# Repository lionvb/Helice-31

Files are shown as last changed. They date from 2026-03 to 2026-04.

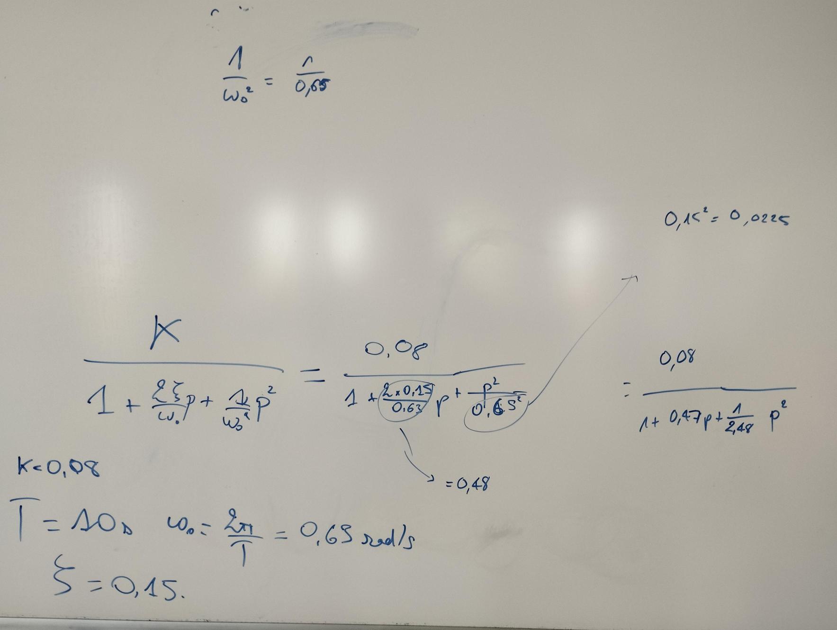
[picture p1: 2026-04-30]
MatLab/image.jpg

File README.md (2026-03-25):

# 🚁 Hélice 31 — Démonstrateur Hélicoptère Asservi

> Maquette transportable de démonstration des compétences en automatique et systèmes embarqués, destinée aux salons et Journées Portes Ouvertes (JPO).

---

## 📋 Présentation du projet

Ce projet consiste à concevoir et réaliser un **démonstrateur interactif en forme d'hélicoptère** capable d'illustrer les compétences E2 en automatique (asservissement PID) et en systèmes embarqués (acquisition, traitement temps réel, commande moteur). La maquette est dimensionnée pour être facilement transportable (≈ 30 × 30 cm) et peut être manipulée en direct par les visiteurs via un boîtier de commande.

---

## 🎯 Objectifs

- Démontrer un **asservissement sur deux axes** (tanguage + anti-couple, comme un quadricoptère)
- Permettre le **réglage en temps réel** des gains PID (Kp, Ki, Kd) par potentiomètres
- Offrir une interface de commande intuitive (potentiomètre ou manette radiofréquence)
- Assurer une **commande numérique temps réel** avec une période d'échantillonnage définie par interruption timer
- Basculer entre correcteur **analogique** et **numérique** 

---

## 🏗️ Architecture du système

```
┌─────────────────────────────────────────────────────────────┐
│                    BOÎTIER DE COMMANDE                       │
│   [Potentiomètre consigne]  [Pot. Kp]  [Pot. Ki]  [Pot. Kd] │
│   [Manette RF optionnelle]                                   │
└─────────────────────────┬───────────────────────────────────┘
                          │  (consigne + gains)
                          ▼
              ┌───────────────────────┐
              │       ARDUINO         │
              │  ┌─────────────────┐  │
              │  │  Timer / IRQ    │  │  ← Période d'échantillonnage fixe
              │  │  Correcteur PID │  │
              │  │  numérique      │  │
              │  └────────┬────────┘  │
              └───────────┼───────────┘
                          │
          ┌───────────────┼───────────────┐
          ▼               ▼               ▼
   [Moteur principal]  [Rotor anticouple]  [LEDs état]
   (tanguage / lift)   (anti-couple)    (saturation, etc.)
          │
          ▼
   [MPU-6050 — mesure angles]
          │
          └──────────────► feedback vers Arduino 
```

### Logique de commande anti-couple 

| Action sur le rotor anticouple | Effet |
|---|---|
| Diminution de la vitesse | Rotation plus lente dans le sens du couple réactif |
| Augmentation de la vitesse | Rotation dans le sens inverse (compensation accrue) |

---

## 🔧 Matériel

| Composant | Rôle | Remarques |
|---|---|---|
| **Arduino** | Unité de traitement centrale | Gestion timers, PID, PWM |
| **MPU-6050** | Gyroscope / accéléromètre | Mesure des angles à intervalle régulier |
| **Moteurs Brushless** | Propulsion (principal + rotor de queue) | ⚠️ Initialiser à 0 pour déverrouiller la sécurité ESC |
| **ESC** | Contrôleurs moteurs brushless | Signal PWM depuis Arduino |
| **Potentiomètres (×4 min.)** | Consigne + réglage Kp, Ki, Kd | Réglage en direct |
| **Manette RF** | Commande sans fil optionnelle | Module RF à intégrer |
| **Batterie LiPo** | Alimentation moteurs | En premier lieu : générateur de labo |
| **Hélices** | 2 modèles disponibles | Format dirigeable et format drone |
| **LEDs** | Indicateurs d'état | Saturation commande, modes, alarmes |
| **Structure** | Châssis de la maquette | Impression 3D — ≈ 30 × 30 cm |

---

## 💻 Logiciel & Algorithmes

### Boucle de contrôle

La boucle de régulation tourne à **période fixe**, déclenchée par une interruption timer sur l'Arduino :

```
IRQ Timer (période T)
  ├── Lecture MPU-6050 (angle mesuré θ)
  ├── Lecture potentiomètre consigne (θ_ref)
  ├── Lecture Kp, Ki, Kd (potentiomètres dédiés)
  ├── Calcul erreur : e = θ_ref - θ
  ├── Calcul correcteur PID numérique
  ├── Saturation + indication LED
  └── Envoi commande PWM vers ESC
```

---

## 🔩 Points critiques de conception

- **Frottements aux jonctions** : à minimiser impérativement pour ne pas perturber la dynamique
- **Légèreté du montage** : impact direct sur les performances - privilégier l'impression 3D 
- **Sécurité ESC brushless** : les moteurs doivent être initialisés à **0** (signal neutre) pour déverrouiller la sécurité électronique

---

## 📐 Modélisation

Le projet inclut une **double modélisation** :
- Modèle **mécanique / physique** de la maquette (dynamique des rotors, couples, inerties)
- Modèle **Matlab** pour la simulation et la synthèse des correcteurs

---

## 💡 Indicateurs LED

| LED | Signification |
|---|---|
| 🔴 Rouge | Saturation de la commande moteur |

---

## 📅 Planning

| Date | Séance | Contenu |
|---|---|---|
| 19/03 | S1 | Spécification & planning |
| 26/03 | S2 | Étude, CAO, Arduino, schéma global |
| 02/04 | S3 | Intégration / Consigne |
| 23/04 | S4 | Modélisation |
| 30/04 | S5 | Soutenance + Making-off|

---

## ⚠️ Règles de sécurité

1. **Ne jamais tester avec des hélices montées sans la présence d'un enseignant.**
2. Toujours initialiser les ESC à la position neutre (commande = 0) avant mise sous tension.
3. En premier prototype, utiliser un **générateur de laboratoire** (pas de batterie LiPo).
4. Vérifier les réglages PID en simulation Matlab avant de les appliquer sur la maquette réelle.
5. S'assurer que la structure est solidement fixée avant tout essai moteur.

---

## 📚 Références & Ressources

- [Maquette existante — Lien 1](#) *(à compléter)*
- [Maquette existante — Lien 2](#) *(à compléter)*
- Documentation MPU-6050 (InvenSense)
- Documentation Arduino (timers, interruptions)
- Datasheet ESC brushless utilisé

---

*Projet **Hélice 31** — réalisé dans le cadre de la formation — Compétences E2 — Automatique & Systèmes Embarqués en collaboration avec M. Trenchant*

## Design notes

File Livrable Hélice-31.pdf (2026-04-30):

Projet Science de l’ingénieur — Livrable Technique
T. BERNARD, F. COG, N.Coudry, L.BOUYAHI, L.QUIBEUF, V.BON & A.KEMPNICH

# PROJET DE SCIENCE DE L'INGÉNIEUR

## Hélice 31

LIVRABLE TECHNIQUE

De la découverte des composants jusqu'à la maquette physique

Équipe Projet

Tristan BERNARD
Fatihhan COG
Nils COUDRY
Loan BOUYAHI
Louis QUIBEUF
Victor BON
Arthur KEMPNICH

Informations

Domaine : Science de l’ingénieur (SI) Durée : 5 séances
Simulation :
Matériel Principal : Arduino Uno

Ce document est un rapport d'avancement détaillé de notre projet.

Projet Science de l’ingénieur — Hélice-31

## Sommaire

Section | Titre | Page
0 | Page de Garde | 1
Sommaire | Sommaire | 2
1 | Contexte | 3
2 | La théorie — Comprendre avant de construire | 4
2.1 | Le Cerveau et L'Échantillonnage : La carte Arduino | 4
2.2 | Les Sens : Le Gyroscope / Accéléromètre | 4
2.3 | Les Actionneurs : Moteur Brushless et ESC | 4
2.4 | L'Interface Humain-Machine (IHM) : Potentiomètres et Bouton | 5
2.5 | La Signalisation : LED et Résistance | 5
3 | Journal de Bord — Avancement séance par séance | 6
4 | Architecture Technique du Montage | 7
4.1 | Composants | 7
4.2 | Schéma Électronique | 8
4.2.1 | Version avec TM1637 | 8
4.2.2 | Version avec LED | 9
4.3 | Montage Réel | 9-10
5 | Explication du code | 11
5.1 | Découpage Modulaire du Code | 11
5.2 | L'Échantillonnage Temps Réel | 11
5.3 | Modélisation du Correcteur PID Numérique | 11-12
5.4 | Traitement du Signal | 12
5.5 | Interface Homme-Machine et Sécurité | 12
5.6 | Modélisation Numérique et Simulation | 13
5.7 | Obtention des données avec notre montage | 13
6 | MatLab | 14
6.1 | Diagnostic et identification du Système (Boucle Ouverte) | 14
6.2 | Synthèse du Correcteur (La Compensation de Pôles) | 14
6.3 | Validation et analyse des résultats | 14-15
7 | Conclusion | 16
8 | Note de l'Équipe | 17

## 1. Contexte et Cahier des Charges

Ce projet s'inscrit dans le cadre de la mise en pratique et de la valorisation des compétences de la filière E2. L'objectif principal est de concevoir un démonstrateur technique attractif et transportable, destiné à être exposé lors de salons et de Journées Portes Ouvertes (JPO). Prenant la forme d'une maquette d'hélicoptère d'environ 40 par 40 centimètres (réalisée en impression 3D), ce système a pour but d'illustrer concrètement les principes d'asservissement sur deux axes.

D'un point de vue technique, le système s'affranchit d'un pilotage direct depuis Simulink au profit d'une commande numérique embarquée autonome basée sur une carte Arduino et un gyroscope MPU 6050. Le pilotage s'effectuera via un boîtier de commande radiofréquence. L'un des aspects les plus didactiques de ce démonstrateur est sa capacité à être réglé "en direct" : l'utilisateur pourra ajuster les coefficients du correcteur PID (Kp, Ki, Kd) à l'aide de potentiomètres dédiés afin d'observer immédiatement l'impact sur la stabilité, avec l'aide de LED signalant notamment la saturation de la commande. La boucle d'asservissement reposera sur un échantillonnage rigoureux, utilisant les timers (interruptions) pour cadencer la mesure des angles et l'envoi des consignes aux moteurs brushless.

Le développement de cette maquette implique également de relever des défis mécaniques et physiques importants. Une double modélisation est nécessaire : la commande du tangage par le rotor principal génère un couple qui fait tourner la structure. Cette rotation parasite doit être compensée par un rotor de queue dont les variations de vitesse permettront de diriger l'appareil. La réussite du projet reposera sur la minimisation des frottements aux jonctions et sur l'optimisation du poids de l'ensemble.

Enfin, la réalisation de ce projet suivra une méthodologie stricte, débutant par un prototypage sur breadboard. Pour des raisons évidentes de sécurité, aucun test impliquant les hélices ne sera toléré sans la supervision du professeur (avec une attention particulière portée à l'initialisation des moteurs brushless). Le développement autorise l'usage de la documentation en ligne et de l'intelligence artificielle générative, à condition que cette dernière soit utilisée avec discernement (pour éviter les erreurs de génération) et que son usage soit explicitement sourcé. Si le besoin s'en fait sentir, une évolution prévoyant la bascule entre un correcteur analogique et numérique pourra être étudiée en collaboration (tâche attribuable à M. Trenchant).

## 2. La Théorie — Comprendre Avant de Construire

Pour que le démonstrateur "Hélice-31" puisse s'auto-stabiliser selon ses deux axes (tangage et lacet), il est nécessaire de créer une boucle d'asservissement complète. Cette boucle repose sur des composants matériels précis qui interagissent en temps réel. Voici le rôle théorique et physique de chacun d'entre eux.

### 2.1 Le Cerveau et l'Échantillonnage : La Carte Arduino

L'Arduino est le microcontrôleur au cœur du système. Son rôle théorique n'est pas seulement de lire des valeurs, mais d'exécuter la commande numérique.

Dans un système asservi informatiquement, le temps n'est pas continu mais discret. L'Arduino utilise ses timers internes et des interruptions pour définir une période d'échantillonnage stricte (par exemple, toutes les 10 ou 20 ms). À chaque "tic" d'horloge, il exécute la même boucle :

1. Mesure de l'erreur (via le gyroscope).
2. Calcul du correcteur PID.
3. Envoi de la nouvelle consigne aux moteurs.
Cette régularité est indispensable pour que les calculs mathématiques d'intégration (pour le Ki) et de dérivation (pour le Kd) soient justes.

### 2.2 Les Sens : Le Gyroscope / Accéléromètre

Le MPU6050 est une centrale à inertie (IMU) qui permet de mesurer l'angle réel de la maquette.

- Le Gyroscope : Mesure la vitesse de rotation angulaire (en degrés par seconde). Il est ultra-réactif mais accumule des erreurs dans le temps (dérive).
- L'Accéléromètre : Mesure le vecteur de la gravité terrestre pour donner un angle absolu par rapport au sol. Il est très sensible aux vibrations des moteurs.
- Théorie d'utilisation : Le code de l'Arduino devra utiliser un filtre mathématique (souvent un "Filtre Complémentaire") pour fusionner ces deux données et obtenir un angle stable et précis, qui servira de retour pour la boucle d'asservissement.

### 2.3 Les Actionneurs : Moteur Brushless et ESC

Contrairement à un petit moteur à courant continu basique, un moteur "Brushless" (sans balais) est un moteur triphasé. Il ne peut pas fonctionner en le branchant directement sur une batterie.

- L'ESC (Electronic Speed Controller) : C'est le variateur électronique. Il transforme le courant continu de l'alimentation en impulsions triphasées pour faire tourner le moteur.
- Contrôle et Sécurité : L'ESC se pilote via un signal PWM (généré par l'Arduino). Point critique de spécification : Par sécurité absolue (surtout lors de l'utilisation d'hélices), un ESC possède une sécurité au démarrage. Il exige de recevoir un signal correspondant à "0% de puissance" pendant quelques secondes à l'allumage pour s'armer, sinon il bloque le moteur.

### 2.4 L'Interface Humain-Machine (IHM) : Potentiomètres et Bouton

Le boîtier de commande permet d'interagir avec le système numérique en temps réel, sans avoir à recompiler le code.

- Le Potentiomètre : Sur le plan théorique, c'est un pont diviseur de tension. L'Arduino lit une tension analogique comprise entre 0V et 5V, qu'il convertit en une valeur numérique (de 0 à 1023).
Vout = Vin*(R2/(R1+R2)
Dans notre projet, ils auront deux rôles : définir la consigne de vol (le point d'équilibre désiré), et surtout, régler en direct les coefficients Kp, Ki et Kd de l'asservissement.
- Le Bouton poussoir : Il servira d'entrée numérique logique (0 ou 1) pour déclencher des actions spécifiques (réinitialisation des intégrateurs du PID, bascule entre modes analogique/numérique, ou arrêt d'urgence).

### 2.5 La Signalisation : LED et Résistance

Les LEDs permettront un diagnostic visuel rapide de l'état du système (ex: LED allumée si la commande sature, signifiant que le moteur est à 100% de ses capacités mais n'arrive pas à atteindre la consigne).

- La Résistance de protection : Une LED est un composant non linéaire qui ne limite pas le courant qui la traverse. Sans résistance, elle grillerait instantanément. La valeur de la résistance est calculée grâce à la loi d'Ohm pour limiter ce courant :
U = R*I
(Où U est la tension aux bornes de la résistance, et I le courant souhaité pour la LED).

## 3. Journal de Bord — Avancement Séance par Séance

Séance 1

Découverte du projet
- Découverte du projet et du cahier des charges.
- Attribution des tâches au sein de l'équipe et découverte du matériel.
- Premières idées et ébauche du schéma de principe (sur papier).

Séance 2

Etude du matériel
- Étude technique approfondie du matériel.
- Début du schéma électronique.
- Initialisation de l'architecture du code Arduino.

Séance 3

Finalisation schéma et début montage
- Finalisation du schéma électronique et de ses variations.
- Début du montage matériel sur breadboard.
- Amélioration et développement de la logique du code.

Séance 4

Finalisation schéma et code
- Prototype matériel terminé.
- Tests de validation des signaux et du code sans hélice pour des raisons de sécurité.
- Compilation et rédaction de la version finale du livrable.

Séance 5

Soutenance
- Présentation orale devant jury.
- Démonstration du montage fonctionnel.

## 4. Architecture Technique du Montage

### 4.1 Composant

Composant | Rôle
Carte Arduino | Le cerveau du système. Elle exécute le code en temps réel, lit les données des capteurs et des potentiomètres, calcule l'asservissement et envoie les ordres de puissance aux moteurs
Moteur Brushless | L'actionneur mécanique. Il transforme l'énergie électrique en une rotation mécanique à très haute vitesse. Il ne possède pas de frottements internes (pas de balais), ce qui le rend ultra-réactif pour stabiliser la maquette.
ESC | Le traducteur de puissance. L'Arduino ne peut pas alimenter directement un gros moteur. L'ESC reçoit le signal de commande faible (PWM) de l'Arduino et libère l'énergie correspondante du générateur vers le moteur sous forme de courant triphasé.
Potentiomètre | L'interface de commande. Il agit comme un diviseur de tension variable. Il permet à l'opérateur de donner une consigne de vol ou de régler en direct les coefficients mathématiques du système.
LED | L'indicateur de diagnostic. Elle fournit un retour visuel instantané (ex: allumée quand le système est initialisé, clignotante lors d'une saturation de commande ou d'une erreur technique).
Bouton | L'entrée logique (0 ou 1). Dans notre projet, le bouton poussoir ne sert pas uniquement de simple interrupteur, mais de sélecteur de mode (bouton modal). Cette approche logicielle permet de maximiser l'utilisation d'un seul potentiomètre pour contrôler plusieurs paramètres du système.
Gyroscope (MPU-92.65) (Changement par manque de matériel) | Le capteur d'attitude. Il mesure en permanence l'accélération terrestre et la vitesse de rotation de la maquette. Il permet au système de connaître son angle exact d'inclinaison physique pour fermer la boucle d'asservissement.
Hélice | Le convertisseur aérodynamique. Elle transforme la rotation mécanique du moteur Brushless en force de poussée. C'est elle qui crée la force physique permettant au bras articulé de vaincre la gravité.
BreadBoard | Le support de prototypage. Elle permet de connecter tous les composants électroniques de manière sécurisée et rapide, sans aucune soudure, ce qui est idéal pour faire des tests ou corriger le schéma.
Cable | Les fils assurent deux missions : transporter l'énergie électrique (VCC, GND) et acheminer les signaux d'information (données des capteurs, signaux PWM) entre la carte et les périphériques.
Générateur | La source d'énergie constante. Utilisé à la place d'une batterie, il garantit une tension électrique parfaitement stable pendant les tests, évitant ainsi que la baisse de tension d'une batterie qui se vide ne fausse le comportement des moteurs et les calculs d'asservissement.

### 4.2 Schéma Électronique

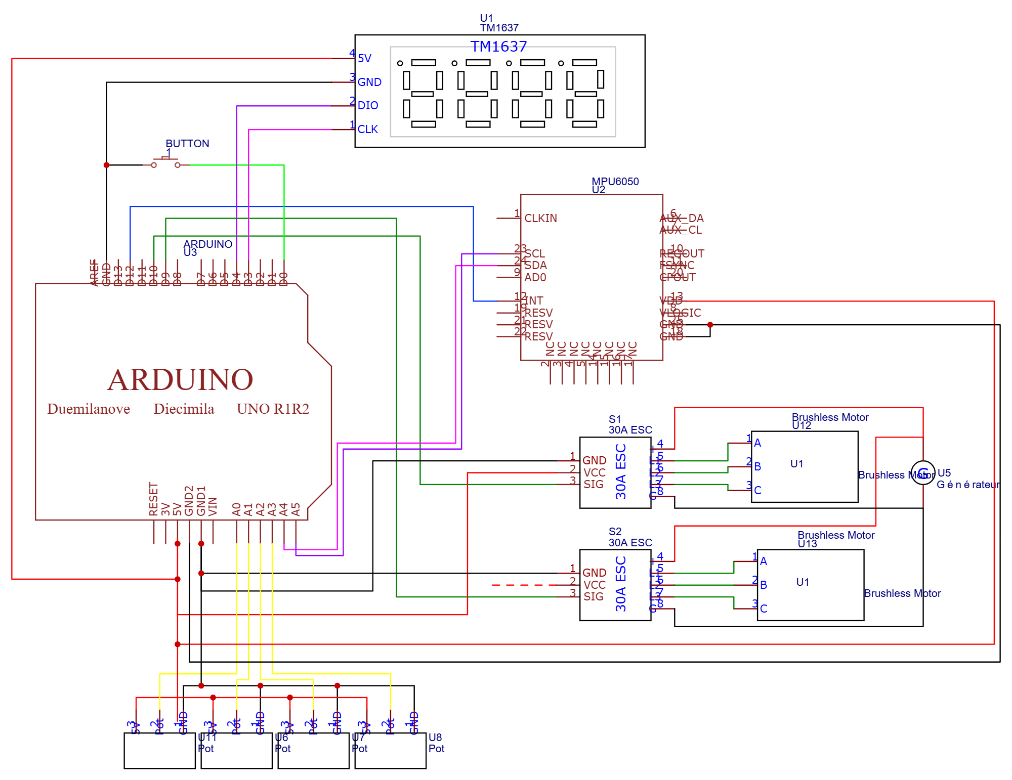
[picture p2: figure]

4.2.1 Version avec TM1637 :

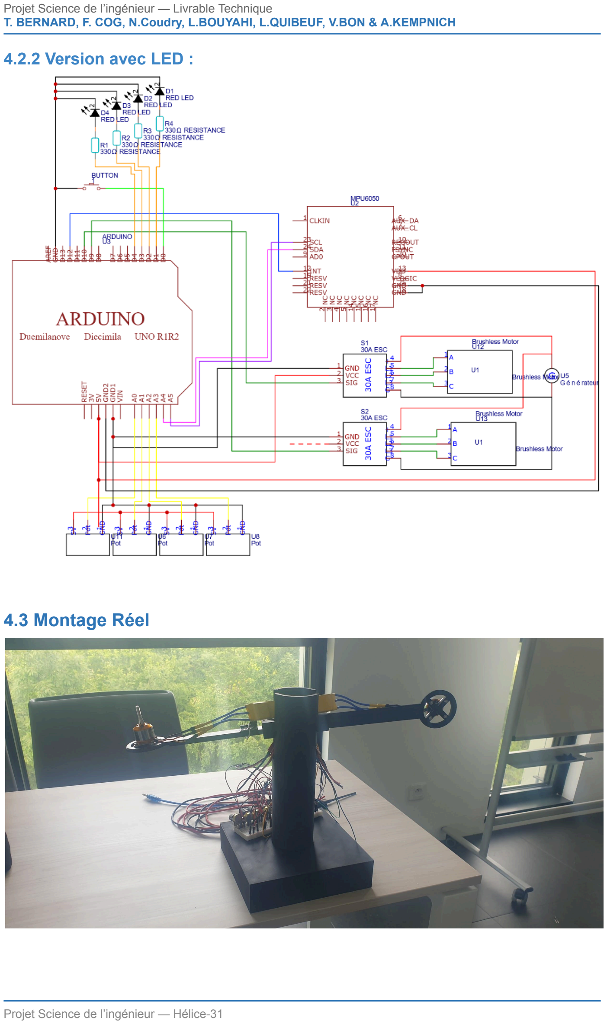
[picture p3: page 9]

### 4.2.2 Version avec LED :

### 4.3 Montage Réel

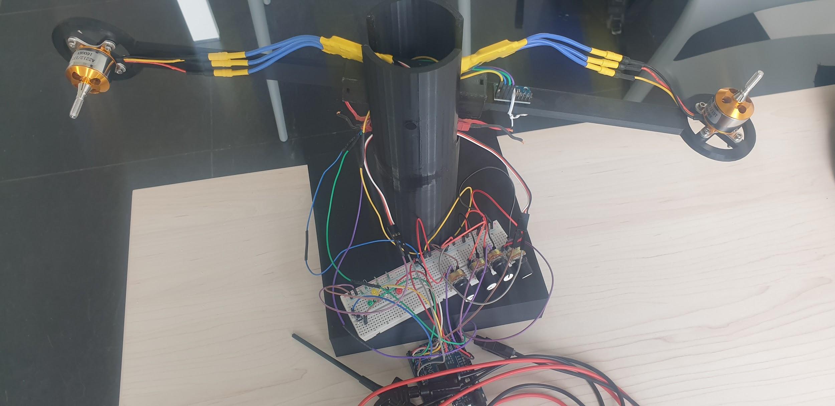
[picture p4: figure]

## 5. Explication du code

### 5.1 Découpage Modulaire du Code

Le projet est divisé en plusieurs fichiers distincts pour séparer la configuration, les mathématiques, la lecture des capteurs et le pilotage des actionneurs.

Module | Fichiers | Rôle technique
Programme Principal | Helice31.ino | Contient les boucles setup() et loop(). Il orchestre l'appel de toutes les fonctions selon un ordonnancement précis dicté par les interruptions du Timer.
Configuration | config.h | Regroupe toutes les constantes du système : période d'échantillonnage (Te = 0.1s), affectation des broches (Pins), limites PWM et valeurs maximales des gains.
Capteurs & Filtres | gyro.cpp / .h | Gère la communication I2C avec le MPU-6050 et implémente le filtre complémentaire pour fusionner les données du gyroscope et de l'accéléromètre.
Asservissement | pid.cpp / .h | Cœur mathématique du système. Calcule la commande (Up, Ui, Ud) en fonction de l'erreur, tout en mémorisant l'état précédent.
Actionneurs | moteurs.cpp / .h | Gère la conversion de la commande (0-100) en signal PWM (1000-2000 µs) via la bibliothèque Servo.h et assure la sécurité d'armement des ESC.
Interface Utilisateur | moteurs.cpp / .h | Gèrent la lecture des potentiomètres, la machine à états du bouton (cycle de réglage Kp/Ki/Kd) avec anti-rebond, et le retour visuel par LED.

### 5.2 L'Échantillonnage Temps Réel

L'une des contraintes majeures de la commande numérique est le respect strict de la période d'échantillonnage (Te = 0.1s). Si la boucle tourne de manière aléatoire, les calculs de dérivation et d'intégration du PID deviennent faux.

Pour éviter cela, nous avons configuré le Timer 2 de l'Arduino en mode CTC (Clear Timer on Compare Match).

1. Une interruption matérielle (ISR(TIMER2_COMPA_vect)) se déclenche à un intervalle précis.
2. Cette interruption ne fait qu'une seule chose : elle lève un drapeau (flag_echantillon = true).
3. La boucle loop() principale attend que ce drapeau soit levé pour exécuter les calculs critiques (lecture angles, calcul PID, envoi moteurs), garantissant un séquencement temporel rigoureux.

### 5.3 Modélisation du Correcteur PID Numérique

L'algorithme du correcteur PID a été discrétisé pour fonctionner sur le microcontrôleur. L'erreur est calculée à chaque instant n: erreur = consigne - mesure.

Dans le fichier pid.cpp, les trois actions sont calculées de la manière suivante :

- Action Proportionnelle (Up) : Directement liée à l'erreur actuelle.
Up = Kp * erreur
- Action Intégrale (Ui) : Utilise la méthode d'intégration trapézoïdale pour limiter les erreurs de calcul numériques. Elle mémorise l'intégrale précédente pour cumuler l'erreur dans le temps.
Ui = Uiprec + ((Ki * Te)/2) * (erreur - erreurprec)
- Action Dérivée Filtrée (Ud) : La dérivation numérique pure amplifie fortement le bruit des capteurs. Un filtre de constante Nfiltre est appliqué pour adoucir le signal de la dérivée tout en gardant sa réactivité.

La commande finale envoyée aux moteurs correspond à la somme des trois actions : Un = Up + Ui + Ud.

### 5.4 Traitement du Signal

Le signal brut du MPU-6050 n'est pas exploitable tel quel. Les vibrations des moteurs faussent l'accéléromètre, et le gyroscope dérive dans le temps. La fonction mettreAJourFiltreComp() implémente un filtre qui s'appuie sur les points forts de chaque capteur :

1. L'intégration du gyroscope réagit très vite aux changements d'angle brusques.
2. L'accéléromètre donne une référence absolue sur le long terme grâce à la gravité terrestre.
3. Une composante de redondance permet même de basculer sur les capteurs mécaniques (potentiomètres) en cas de défaillance de la communication I2C au démarrage (gyroDisponible = false).

### 5.5 Interface Homme-Machine et Sécurité

Le code a été conçu pour permettre un réglage optimal lors des démonstrations :

- Multiplexage des commandes : Afin de limiter le câblage, un seul potentiomètre sert à régler les gains. Le bouton poussoir permet de cycler la sélection (Kp -> Ki -> Kd -> Kp). La fonction majSelectionGain() intègre un système d'anti-rebond temporel (Debounce de 50ms) pour éviter les sauts intempestifs.
- Diagnostic Visuel : Des LED informent l'utilisateur du paramètre en cours de réglage. Une LED rouge dédiée est gérée par la fonction estEnSaturation() ; elle s'allume instantanément si l'algorithme demande une puissance moteur en dehors des limites physiques (inférieure à 0 ou supérieure à la limite maximale fixée).
- Sécurité Matériel (ESC) : Au démarrage (initMoteurs()), le code impose un blocage absolu du programme de 3 secondes en envoyant un signal PWM minimum (1000 µs). Cette séquence est vitale et exigée par les contrôleurs Brushless pour déverrouiller la rotation.

### 5.6 Modélisation Numérique et Simulation

En début de projet, l'absence de capteur inertiel matériel nous a conduits à développer un simulateur mathématique en boucle ouverte pour ne pas bloquer notre avancée. Ce code d'attente modélisait la physique des axes de tangage et de lacet directement sur l'Arduino.

Le programme utilisait la méthode d'intégration numérique d'Euler : il traduisait la consigne des potentiomètres en force, puis calculait en temps réel l'accélération, la vitesse, et enfin l'angle de la maquette. Pour être réaliste, le modèle prenait en compte l'inertie, les frottements, la gravité terrestre, le couplage entre les axes et l'effet gyroscopique.

Cependant, l'intégration d'Euler accumule inévitablement des erreurs de calcul, provoquant une dérive de l'angle estimé après une trentaine de secondes. Ce "gyroscope virtuel" n'a donc pas été conservé dans la version finale : nous avons finalement réussi à nous procurer un véritable capteur physique. Nous avons même pu faire évoluer notre choix initial (le MPU-6050) vers un modèle MPU-92.65 pour assurer un asservissement direct, stable et beaucoup plus fiable.

### 5.7 Obtention des données avec notre montage

Ce script a été spécifiquement développé pour caractériser la réponse dynamique du système. Il applique automatiquement un échelon de commande de 0.6V et réalise une acquisition des données avec une période d'échantillonnage stricte de 50ms. Ces paramètres permettent de tracer la courbe d'évolution temporelle avec une excellente résolution, facilitant ainsi l'analyse du régime transitoire et l'extraction des données de performance.

## 6. MatLab

### 6.1 Diagnostic et Identification du Système (Boucle Ouverte)

Avant de chercher à contrôler l'hélicoptère, il fallait comprendre sa dynamique naturelle. Nous avons injecté un échelon simple (1V) dans le modèle State-Space de la maquette, sans aucun correcteur.

L'analyse de cette réponse nous a permis d'identifier la Fonction de Transfert en Boucle Ouverte (FTBO) de notre système sous sa forme canonique du second ordre :

Hp = (0,08)/(2,48p^2 + 0,47p +1)

Cette équation traduit parfaitement la "personnalité" physique de la machine :

- Un système "lourd" : Le gain statique très faible ($K=0,08$) indique qu'il faut fournir beaucoup d'énergie pour obtenir un mouvement significatif.
- Un comportement très oscillant : Le système présente un sous-amortissement chronique (ε ≈ 0,15 ). Naturellement, le bras manque de friction et oscille longuement avant de se stabiliser.
- Une dynamique lente : La pulsation propre ω0 de 0,635 rad/s confirme une inertie importante.

### 6.2 Synthèse du Correcteur (La Compensation de Pôles)

Pour corriger ces défauts, nous avons utilisé la méthode mathématique de la compensation de pôles. L'objectif est de configurer le régulateur PID pour que son équation annule exactement les termes gênants du dénominateur de la machine (ceux qui causent les oscillations, soit les coefficients 0,47 et 1).

Ensuite, nous avons appliqué un gain global (A=18,75) pour forcer le système à atteindre sa cible en environ 2 secondes. Cette chirurgie mathématique nous a donné des gains réalistes et optimisés, compatibles avec nos actionneurs réels :

- Gain Proportionnel (Kp) : 8,8
- Gain Intégral (Ki) : 18,75
- Gain Dérivé (Kd) : 46,5

### 6.3 Validation et Analyse des Résultats

Nous avons ensuite simulé l'impact de ce nouveau régulateur PID sur deux modèles distincts pour valider notre approche.

### 1. Sur la Fonction de Transfert Théorique :

Lorsqu'on applique le PID à notre fonction de transfert mathématique $H(p)$, la réponse est parfaite. La courbe monte rapidement, atteint la consigne exacte de 1,0 sans aucun dépassement, et se stabilise instantanément. Dans ce monde mathématique idéal, le PID a parfaitement annulé les pôles oscillants du système.

### 2. Sur le Modèle "State-Space" Réel :

Nous avons ensuite appliqué ce même PID au modèle State-Space complet (qui inclut des comportements plus proches de la réalité de notre maquette).

Contrairement à nos premières simulations avec des gains extrêmes (qui plafonnaient à 0,87), le système atteint cette fois-ci parfaitement la consigne de 1,0. L'erreur statique a totalement disparu.

Nous observons cependant quelques oscillations résiduelles au démarrage. Celles-ci s'expliquent par trois facteurs inhérents au passage de la théorie à la pratique :

- La complexité du modèle : Le modèle State-Space contient des petites non-linéarités que notre fonction de transfert simplifiée du second ordre n'a pas pu capter à 100 %.
- La Saturation (Windup) : Lors de la montée brusque, les moteurs buttent contre leurs limites physiques (alimentation de 12V), ce qui perturbe l'action initiale du PID.
- Le filtre de la dérivée : Le filtrage indispensable du gain Kd modifie légèrement le calcul en temps réel, empêchant l'annulation mathématique d'être absolument parfaite.

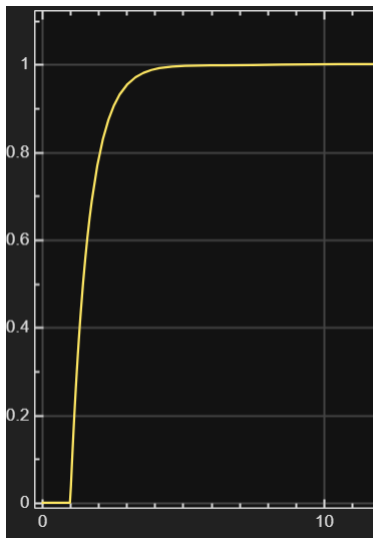
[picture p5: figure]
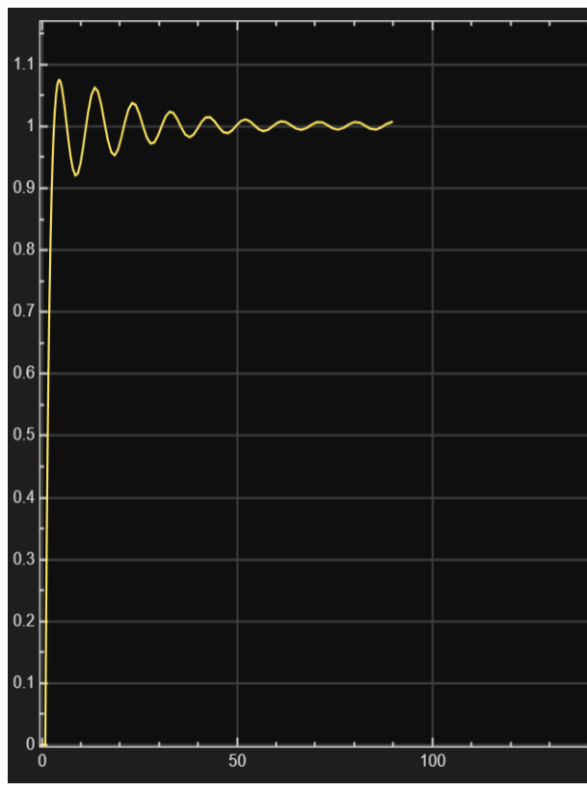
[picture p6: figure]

Cette démarche nous a permis de
passer d'un système qui oscillait
dans le vide ou plafonnait sous la contrainte, à un système asservi capable de suivre précisément sa consigne en compensant sa propre inertie physique.

Figure 1 : Réponse du modèle théorique (PID sur Fonction de Transfert) —>

Figure 2 : Réponse du modèle réel (PID sur State-Space) —>

## 7. Conclusion

Le projet "Hélice-31" a pleinement atteint son objectif principal : concevoir un démonstrateur technique attractif et transportable, parfaitement adapté pour être exposé lors des Journées Portes Ouvertes (JPO). Nous avons réussi à transformer un concept théorique d'asservissement sur deux axes en une maquette physique fonctionnelle et interactive.

D'un point de vue technique, le passage d'un pilotage direct depuis Simulink à une commande numérique embarquée autonome sur Arduino a été un succès. La mise en place d'un échantillonnage rigoureux via les interruptions matériels (timers) a permis de garantir la stabilité de notre correcteur PID. De plus, l'interface homme-machine conçue permet un réglage didactique en direct des coefficients (Kp, Ki, Kd), illustrant concrètement l'impact de l'asservissement à tout utilisateur.

Ce projet nous a également confrontés à la réalité de l'ingénierie matériel. Qu'il s'agisse de la gestion stricte de la sécurité au démarrage des moteurs Brushless , de la minimisation des frottements mécaniques , ou encore de l'adaptation face au manque de composants, chaque défi a été surmonté. L'intégration finale du capteur MPU-92.65 a couronné ces efforts en offrant un asservissement direct et fiable.

En perspective d'évolution, comme évoqué dans le cahier des charges, il serait intéressant de développer la bascule entre un correcteur analogique et numérique , ainsi que de finaliser l'intégration complète du pilotage par boîtier de commande radiofréquence.

## 8. Note de l'Équipe

Note personnelle de l'équipe projet

La réalisation de la maquette Hélice-31 a été une aventure technique et humaine extrêmement enrichissante pour l'ensemble de notre groupe (Tristan, Fatihhan, Nils, Loan, Louis, Victor et Arthur). Ce projet nous a permis de faire le pont entre les équations mathématiques pures vues en classe et le comportement physique réel des composants électroniques et mécaniques.

Nous tenons tout particulièrement à remercier nos professeurs, M. Trenchant et M. Schlinquer, pour leur accompagnement, leur supervision et de leur aide tout au long de ces 5 séances. Voir notre hélicoptère fonctionner après des heures de codage, de modélisation et de câblage restera l'une des plus belles récompenses de notre formation en Sciences de l'Ingénieur.

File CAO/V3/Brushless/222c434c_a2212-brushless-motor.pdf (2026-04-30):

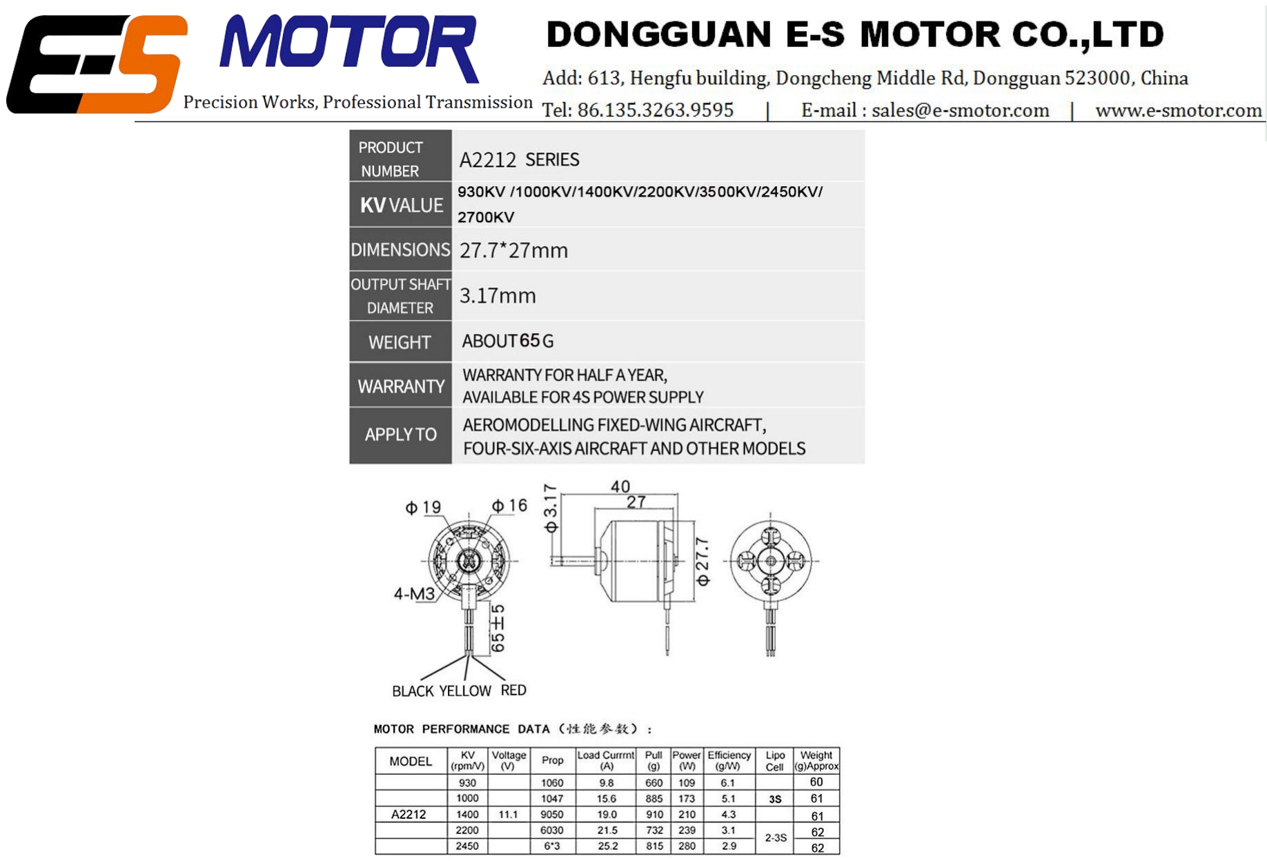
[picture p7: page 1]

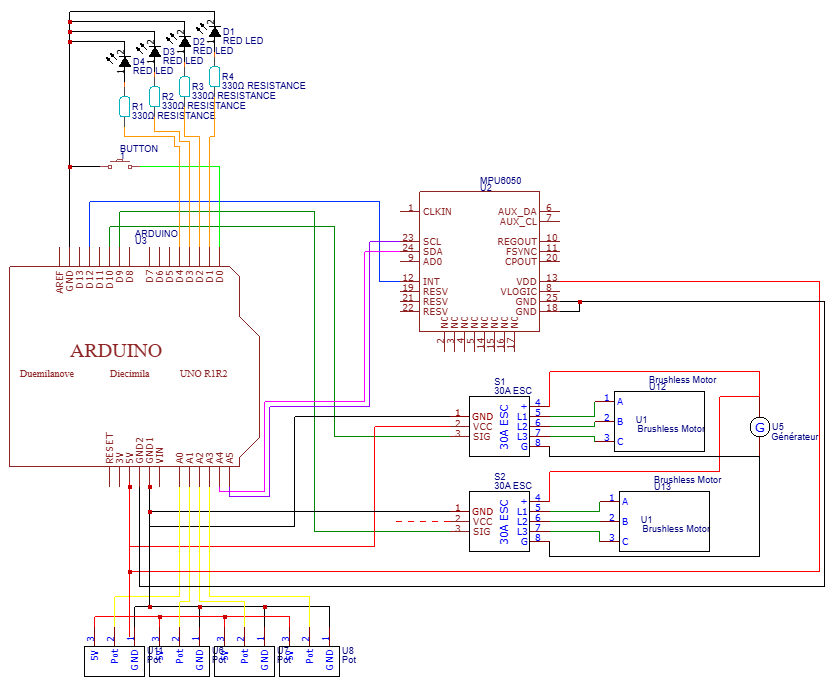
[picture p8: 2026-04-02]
Hardware/Hélice31-LED (1).png

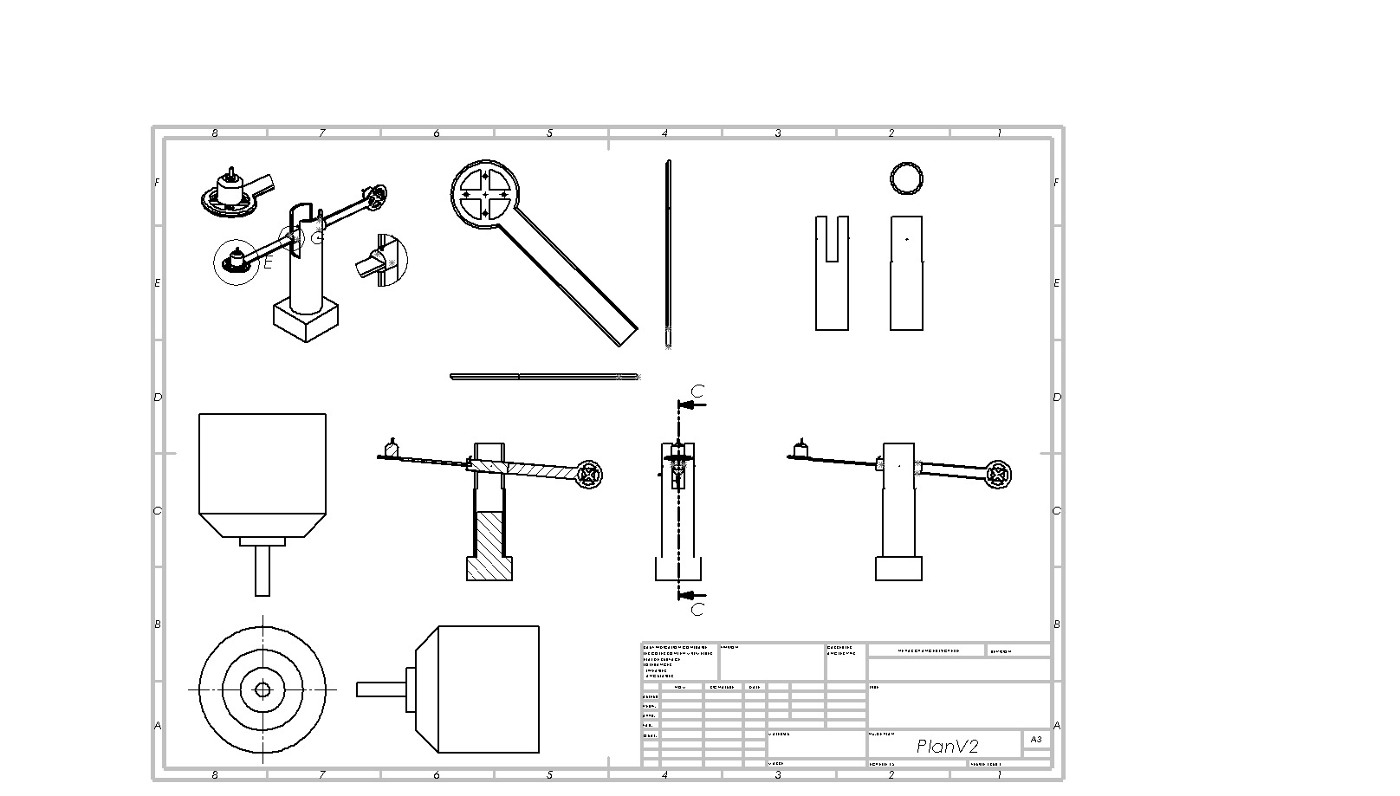
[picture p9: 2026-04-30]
CAO/V3/PlanV2.JPG

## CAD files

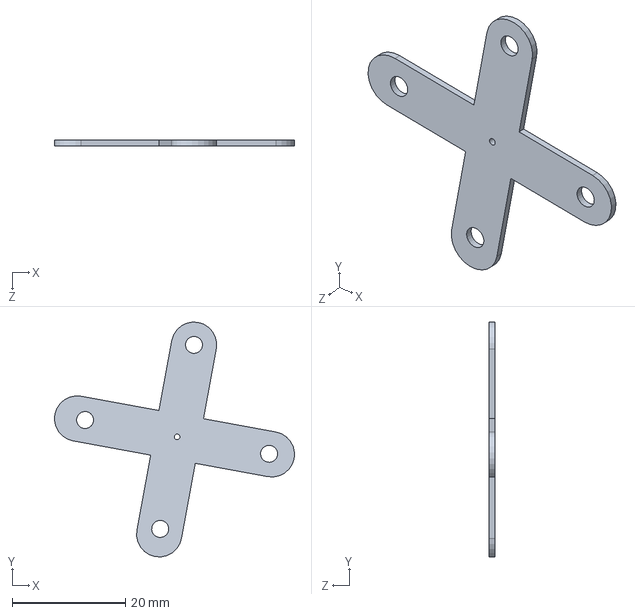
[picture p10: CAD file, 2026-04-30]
CAO/V3/Brushless/Brushless complet.SLDASM
42.3 x 41.4 x 1.00 mm

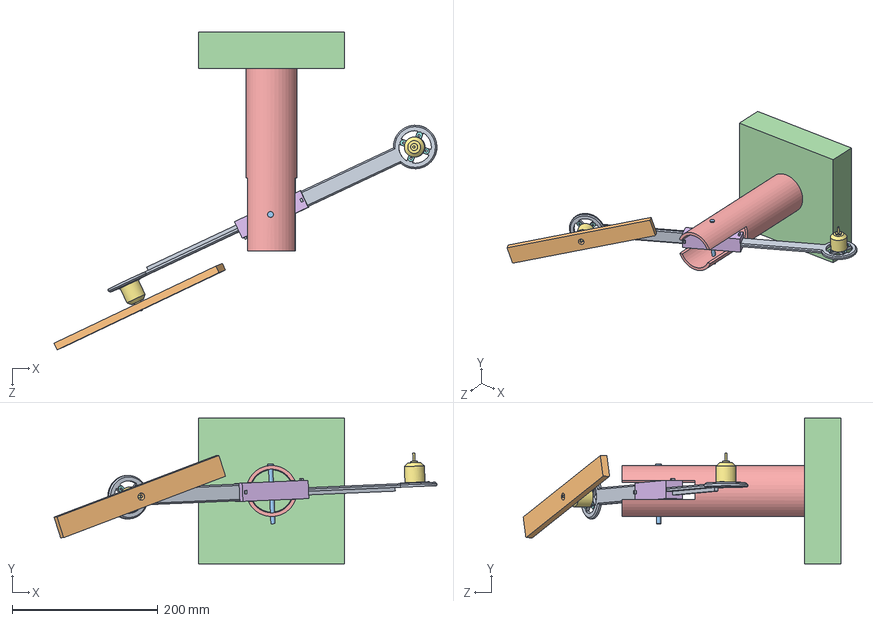
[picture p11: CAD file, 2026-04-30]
CAO/V3/Assemblage V2.SLDASM
525.3 x 200.0 x 435.7 mm
support brushless - Copie x 2
support brushless x 2
Corps brushless x 2
Support bras
corps partie movible
corps partie fixe
axe corps
hélice
Pièce2 x 2

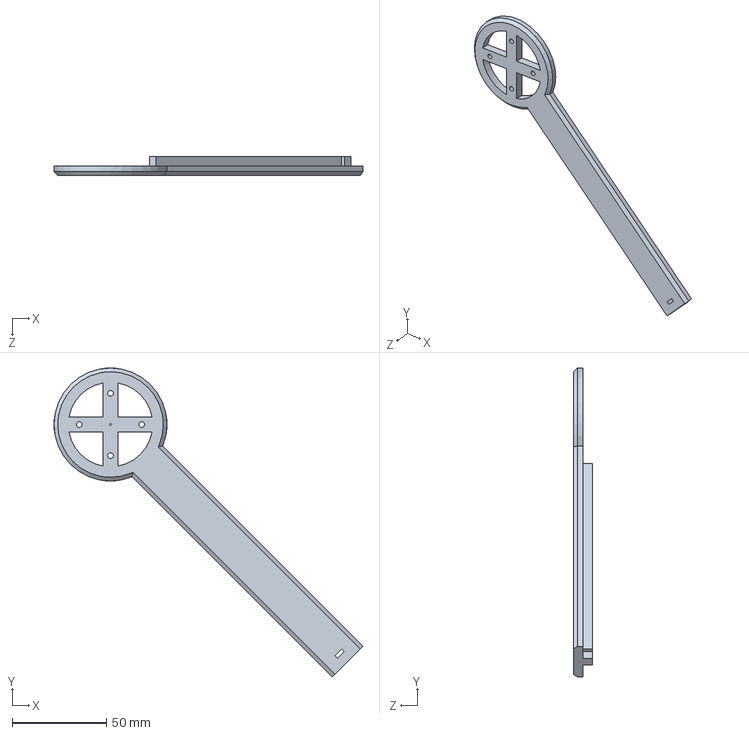
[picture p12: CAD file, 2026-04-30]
CAO/V3/Bras/support brushless - Copie.SLDPRT
163.7 x 163.7 x 10.0 mm

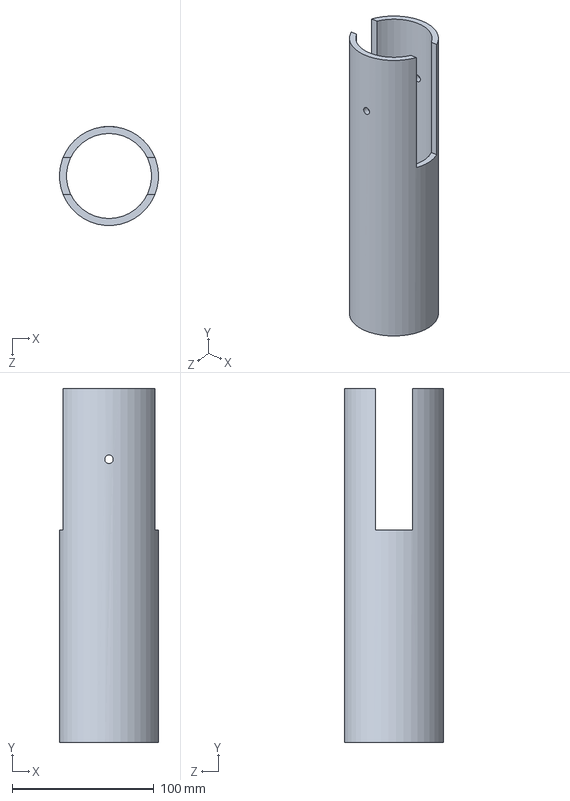
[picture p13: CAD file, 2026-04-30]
CAO/V3/Corps/corps partie movible.SLDPRT
69.9 x 250.0 x 70.0 mm

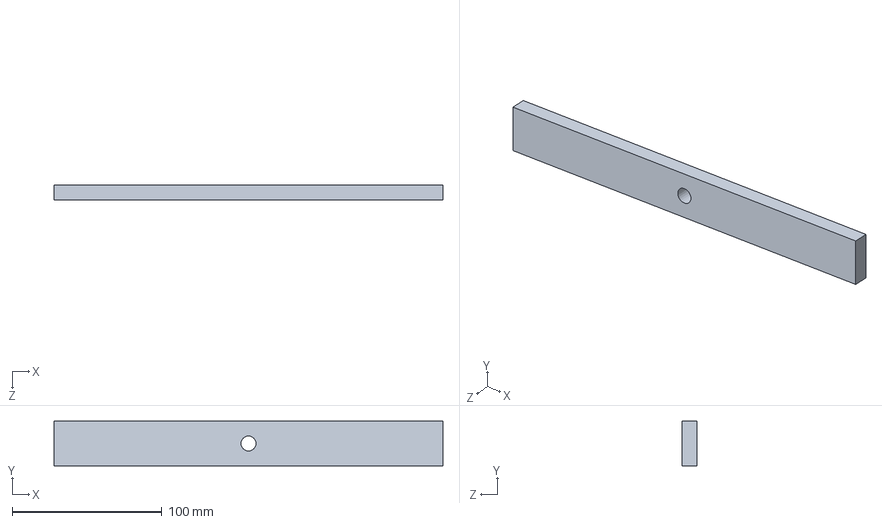
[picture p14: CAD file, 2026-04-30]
CAO/V3/hélice.SLDPRT
260.0 x 30.0 x 10.0 mm

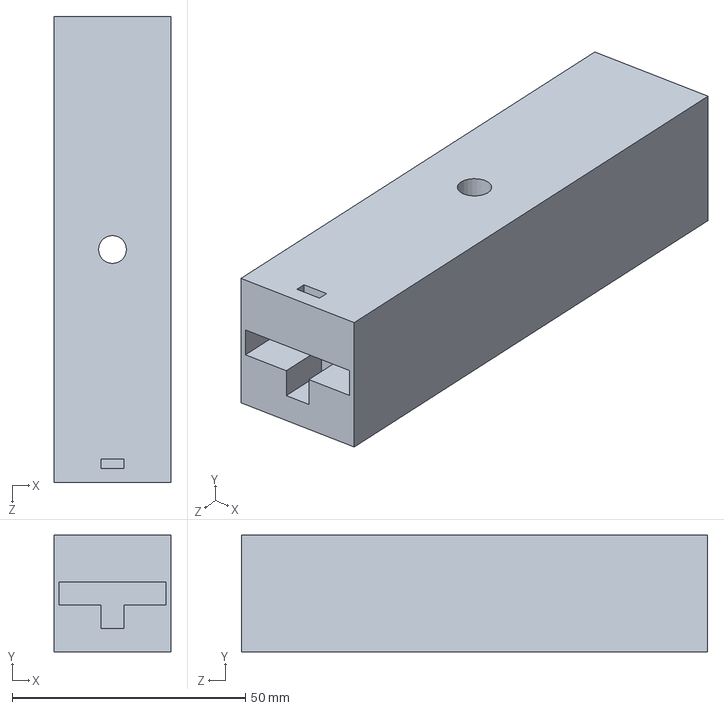
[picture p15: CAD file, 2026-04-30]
CAO/V3/Bras/Support bras.SLDPRT
25.0 x 25.0 x 100.0 mm

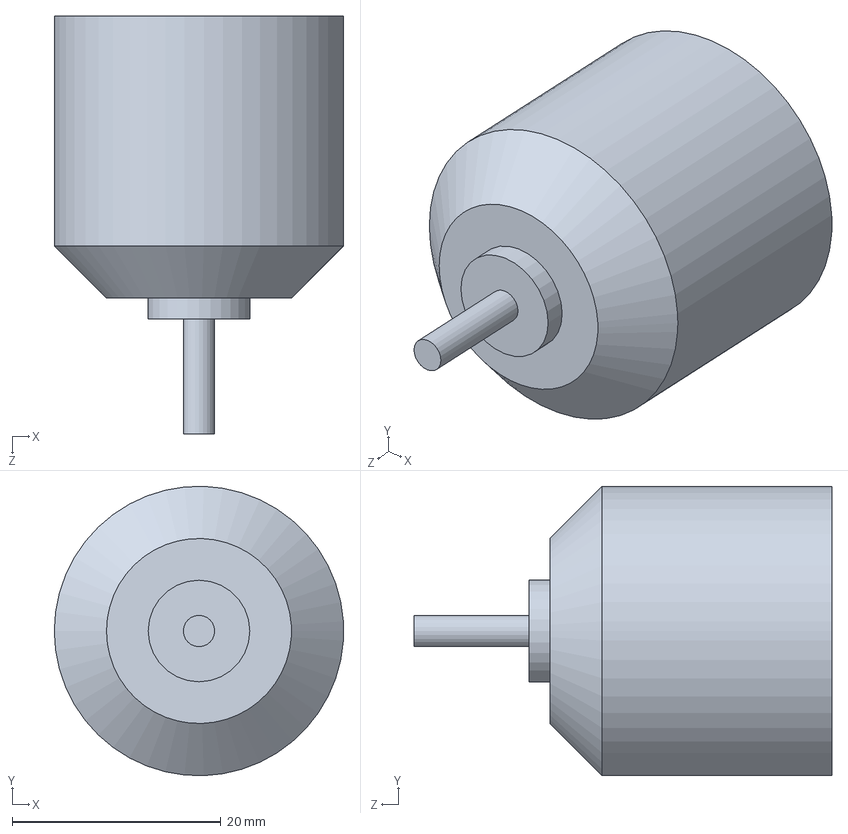
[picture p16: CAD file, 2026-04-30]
CAO/V3/Brushless/Corps brushless.SLDPRT
27.7 x 27.7 x 40.0 mm

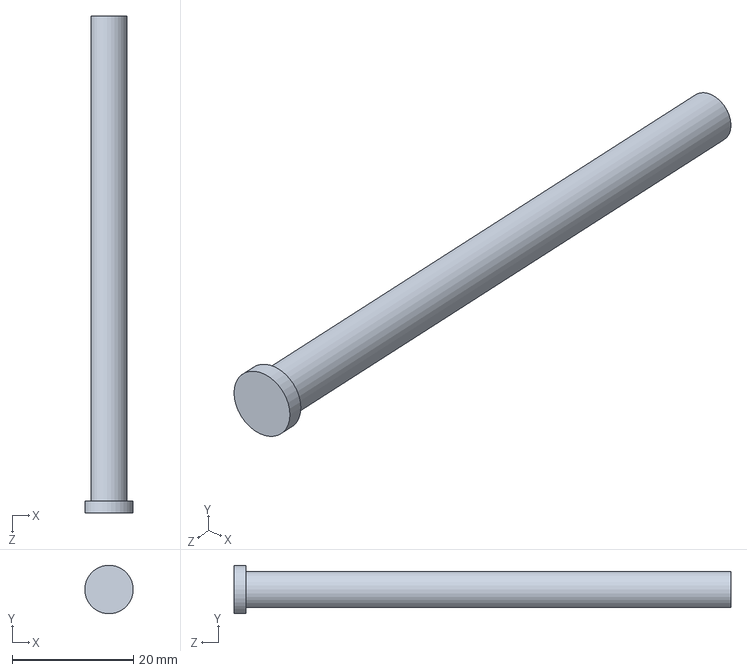
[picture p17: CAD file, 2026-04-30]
CAO/V3/Corps/axe corps.SLDPRT
8.00 x 7.97 x 82.0 mm

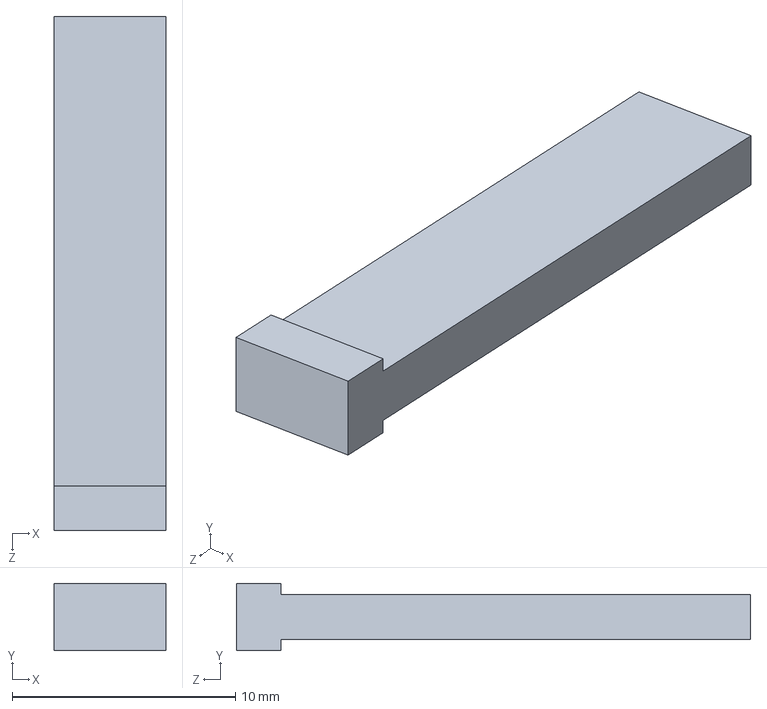
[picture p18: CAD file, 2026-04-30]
CAO/V3/Pièce2.SLDPRT
5.00 x 3.00 x 23.0 mm

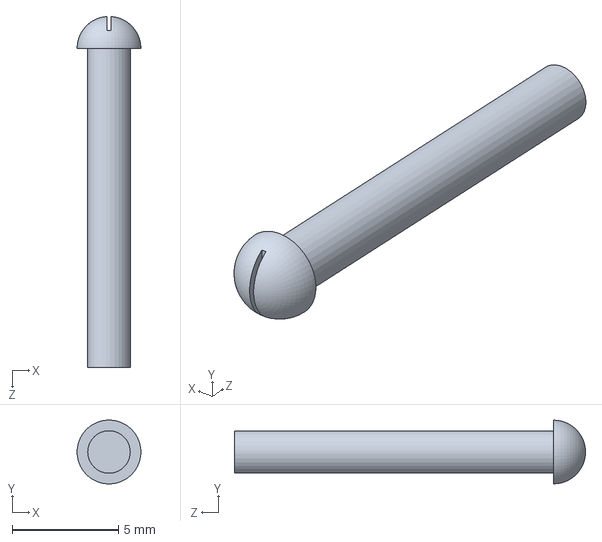
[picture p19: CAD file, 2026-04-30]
CAO/V3/Brushless/Vis bras.SLDPRT
3.00 x 2.99 x 16.5 mm

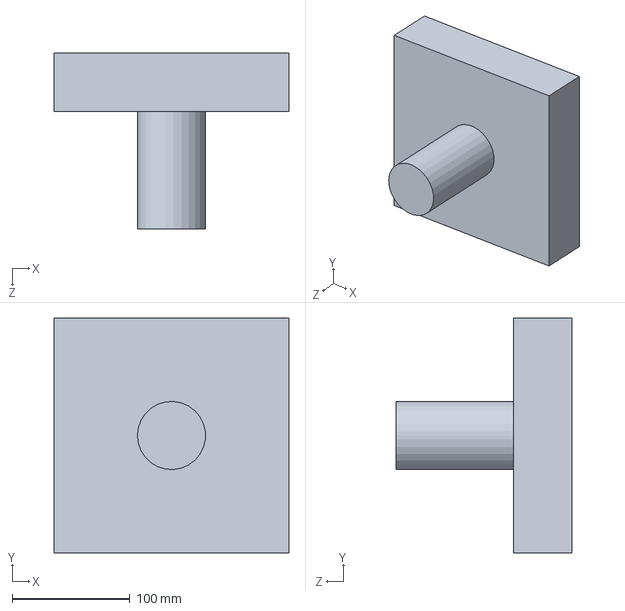
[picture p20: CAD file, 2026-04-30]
CAO/V3/Corps/corps partie fixe.SLDPRT
200.0 x 200.0 x 150.0 mm

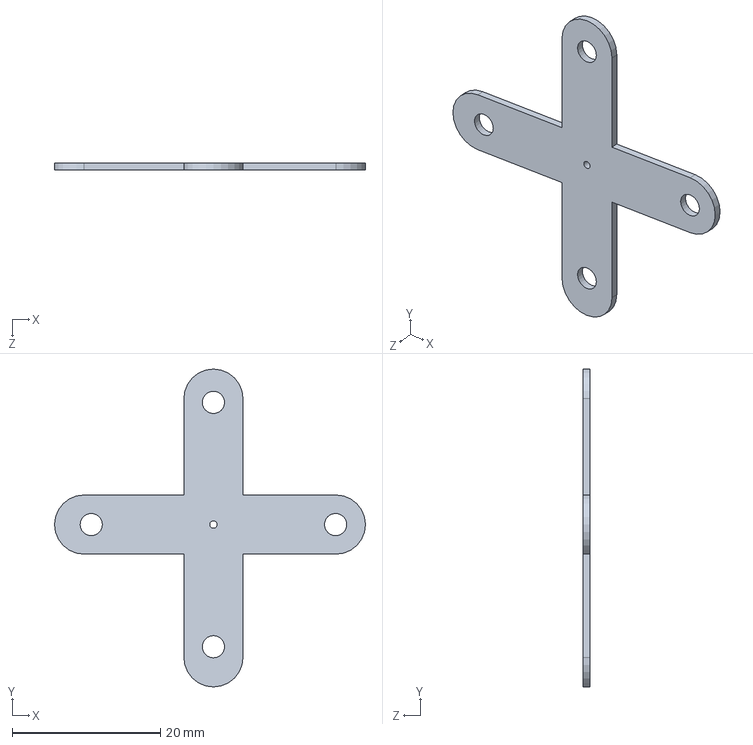
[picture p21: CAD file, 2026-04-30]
CAO/V3/Brushless/support brushless.SLDPRT
42.0 x 42.9 x 1.00 mm

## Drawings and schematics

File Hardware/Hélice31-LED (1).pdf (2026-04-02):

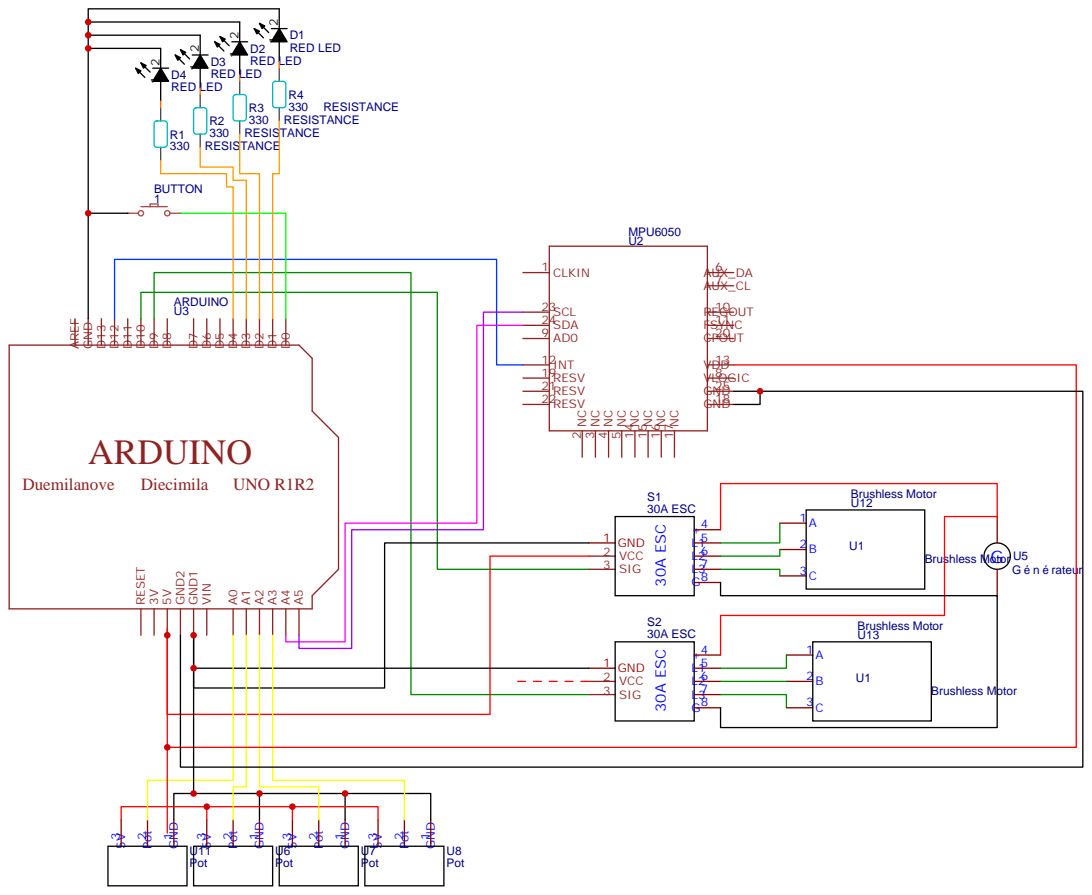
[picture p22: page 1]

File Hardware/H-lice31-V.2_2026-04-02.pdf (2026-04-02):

TM1637

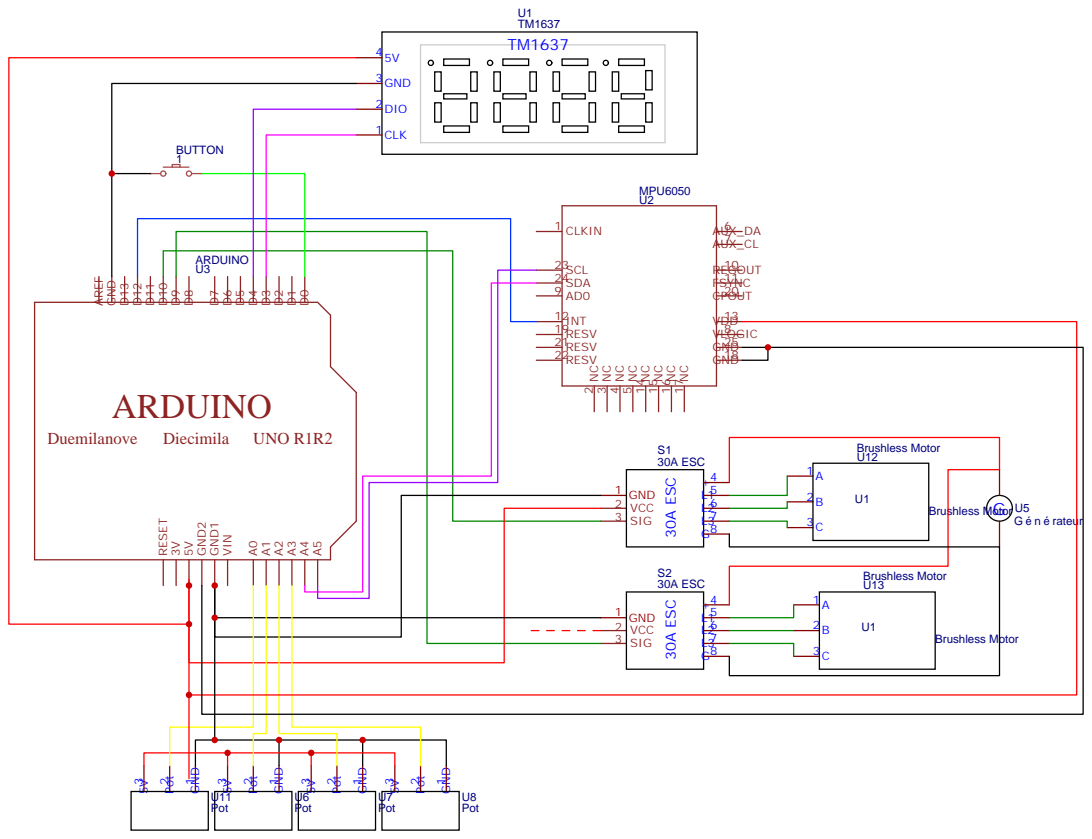
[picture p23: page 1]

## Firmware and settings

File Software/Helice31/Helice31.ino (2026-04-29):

#include "config.h"
#include "gyro.h"
#include "pid.h"
#include "moteurs.h"
#include "commande.h"
#include "leds.h"

//Instances PID
EtatPID pidTanguage;
EtatPID pidLacet;

//Flag levé par l'ISR du Timer2 
volatile bool flag_echantillon = false;

// Watchdog : timestamp de la dernière commande envoyée
// Si trop longtemps sans commande → arretUrgence()
unsigned long derniere_commande_ms = 0;

// ISR Timer12
ISR(TIMER2_COMPA_vect) {
    flag_echantillon = true;
}

//Configuration Timer2 en mode CTC
void initTimer2() {
    noInterrupts();

    TCCR2A = 0;
    TCCR2B = 0;
    TCNT2  = 0;

    OCR2A = 156; // exemple ~10ms

    TCCR2A |= (1 << WGM21); // CTC
    TCCR2B |= (1 << CS22) | (1 << CS21) | (1 << CS20); // prescaler 1024

    TIMSK2 |= (1 << OCIE2A);

    interrupts();
}

void setup() {
    Serial.begin(115200);

    // 1. Gyroscope MPU-6050 + potentiomètres de mesure mécaniques
    initGyro();
    calibrerGyro();      //  hélico immobile obligatoire

    // 2. Moteurs : séquence sécurité ESC (3 s signal neutre)
    initMoteurs();

    // 3. Commande : pot gain, bouton sélection, pot redondance, RF
    initCommande();

    // 4. LEDs (allume LED_KP par défaut)
    initLeds();

    // 5. PID : remise à zéro des deux instances
    resetPID(&pidTanguage);
    resetPID(&pidLacet);

    // 6. Timer en dernier (démarre la boucle temps réel)
    initTimer2();

    if (gyroEstDisponible()) {
        Serial.println("Helice31 pret — mode nominal (gyro + pots)");
    } else {
        Serial.println("Helice31 pret — mode degrade (pots seuls)");
    }
}

void loop() {
    
    //Bouton sélection gain : géré HORS du flag timer
    majSelectionGain();
    majLedsGain(gainActuel());


    //Attendre le tick timer
    if (!flag_echantillon) return;
    flag_echantillon = false;
    
    //1. Mise à jour filtre et lecture angles
    mettreAJourFiltreComp();
    float angleTangage = lireAngleTangage();
    float angleLacet   = lireAngleLacet();

    //2. Lecture consigne 
    // Priorité : RF → pot redondance si RF indispo
    float consigne;
    bool rfOk = rfDisponible();
    if (rfOk) {
        consigne = lireConsigneRF();
    } else {
        consigne = lireConsigneRedondance();
    }

    //3. Lecture gains (pot unique → gain sélectionné)
    float kp, ki, kd;
    lireGains(&kp, &ki, &kd);

    // 4. Correcteur PID axe tanguage
    float cmdPrincipale = calculPID(consigne, angleTangage,kp, ki, kd, &pidTanguage);

    //5. Correcteur PID axe lacet (consigne = 0° : maintenir le cap)
    float cmdLacet = calculPID(0.0f, angleLacet,kp * 0.5f, ki * 0.3f, kd * 0.5f, &pidLacet);
    majLeds(estEnSaturation());
    //6. Envoi commandes moteurs 
    setMoteurPrincipal(cmdPrincipale);
    setRotorQueue(VITESSE_BASE_QUEUE, cmdLacet);

    //7. LEDs saturation + mode 
    delay(500);
    //8. Debug série 
    Serial.print(rfOk ? "RF " : "POT");
    Serial.print(" ref=");  Serial.print(consigne, 1);
    Serial.print(" tan=");  Serial.print(angleTangage, 1);
    Serial.print(" lac=");  Serial.print(angleLacet, 1);
    Serial.print(" u1= ");   Serial.print(cmdPrincipale, 1);
    Serial.print(" u2= ");   Serial.print(cmdLacet, 1);
    Serial.print(" Kp=");   Serial.print(kp, 2);
    Serial.print(" Ki=");   Serial.print(ki, 2);
    Serial.print(" Kd=");   Serial.println(kd, 2);
}

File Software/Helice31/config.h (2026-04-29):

#ifndef CONFIG_H
#define CONFIG_H

//  PARAMÈTRES TEMPS RÉEL

#define TE       0.1f    // Période d'échantillonnage en secondes (0.1s = 100ms)
#define TE_MS    100     // TE en millisecondes (pour le calcul du timer)
#define N_FILTRE 10      // Facteur filtre dérivée (renommé pour éviter conflit)

//  LIMITES COMMANDE PID

#define COMMANDE_MIN     0.0f    // commande minimale (correspond à PWM_MIN)
#define COMMANDE_MAX     100.0f  // commande maximale (correspond à PWM_MAX)


//  PINS MOTEURS

#define PIN_MOTEUR_PRINCIPAL  9
#define PIN_ROTOR_QUEUE       10

//  PINS POTENTIOMÈTRES

#define PIN_POT_ANGLE_TANGAGE A3   // retour mécanique axe tanguage
#define PIN_POT_ANGLE_LACET   A2   // retour mécanique axe lacet
#define PIN_POT_REDONDANCE    A1   // consigne de secours (sans manette RF)
#define PIN_POT_GAIN          A0   // pot unique réglage Kp / Ki / Kd

//  BOUTON SÉLECTION GAIN
#define PIN_BTN_GAIN          6    // pull-up interne

//  PINS LEDs
#define PIN_LED_SATURATION    2    // rouge  — commande saturée  
#define PIN_LED_KP            3   // vert   — on règle Kp
#define PIN_LED_KI            4   // vert   — on règle Ki
#define PIN_LED_KD            5    // vert   — on règle Kd

//  SIGNAL ESC (PWM en µs)

#define PWM_MIN               1000   // moteur à l'arrêt
#define PWM_MAX               2000   // pleine puissance

//  LIMITES GAINS PID

#define KP_MAX                5.0f
#define KI_MAX                2.0f
#define KD_MAX                1.0f

//  CONSIGNE

#define ANGLE_MAX_DEG         30.0f 

//  ROTOR DE QUEUE

#define VITESSE_BASE_QUEUE    40.0f   // régime nominal rotor queue (%)

//  MODES

#define MODE_NUMERIQUE        0
#define MODE_ANALOGIQUE       1

#endif

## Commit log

2026-03-26 Definition du début de la structure
2026-03-26 rectification d'un nom de fichier
2026-03-26 Hélice 31 Architecture electronique
    Différent fichier pour l'Architecture électronique du projet sur Tinkercad, un .png, un .brd et un .txt qui contient le lien tinkercad du projet.
    [Hélice31 Architecture electronique.brd]
2026-03-26 début des inits
2026-03-26 j'espere que je vais pas niquer le gitHub
2026-03-26 Revert "modifs test"
    This reverts commit e78834df086b5f4408c1a55da703ee13fe52c66b.
    [moteurs.cpp]
2026-03-26 Revert "modifs test"
    This reverts commit abb11b996f3aa9a9a522cbe62587114e7f66aabe.
    [leds.cpp]
2026-03-26 code gyro
2026-04-02 Shéma Electrique Final
    Finissions du schéma électrique de Hélice 31.
    [Hélice31-V.2_2026-04-02.schdoc]
2026-04-02 code gyro Corrigé
2026-04-02 code gyro Corrigé 2
    [gyro.cpp]
2026-04-02 Version LED du Schéma Electrique de Hélice31
    J'ai remplace l'afficheur par 4 led
    [Hélice31-LED (1).schdoc]
2026-04-08 Rectification d'un nom de variable et rajout d'un point ;
2026-04-30 ajout de la CAO
    [Assemblage V2.SLDASM, Brushless complet.SLDASM, Corps brushless.SLDPRT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]
2026-04-30 Create Simulation_Tangage_Lacet.ino
    Rajout du gyroscope numérique
2026-04-30 Create Simulation_Tangage_Lacet_Documentation.txt
    Explication du programme pour simuler un gyroscope
2026-04-30 Fichier MatLab
    Les fichiers MatLab de Loan et Nils
2026-04-30 Image MatLab
    Image des résultats et calculs MatLab
